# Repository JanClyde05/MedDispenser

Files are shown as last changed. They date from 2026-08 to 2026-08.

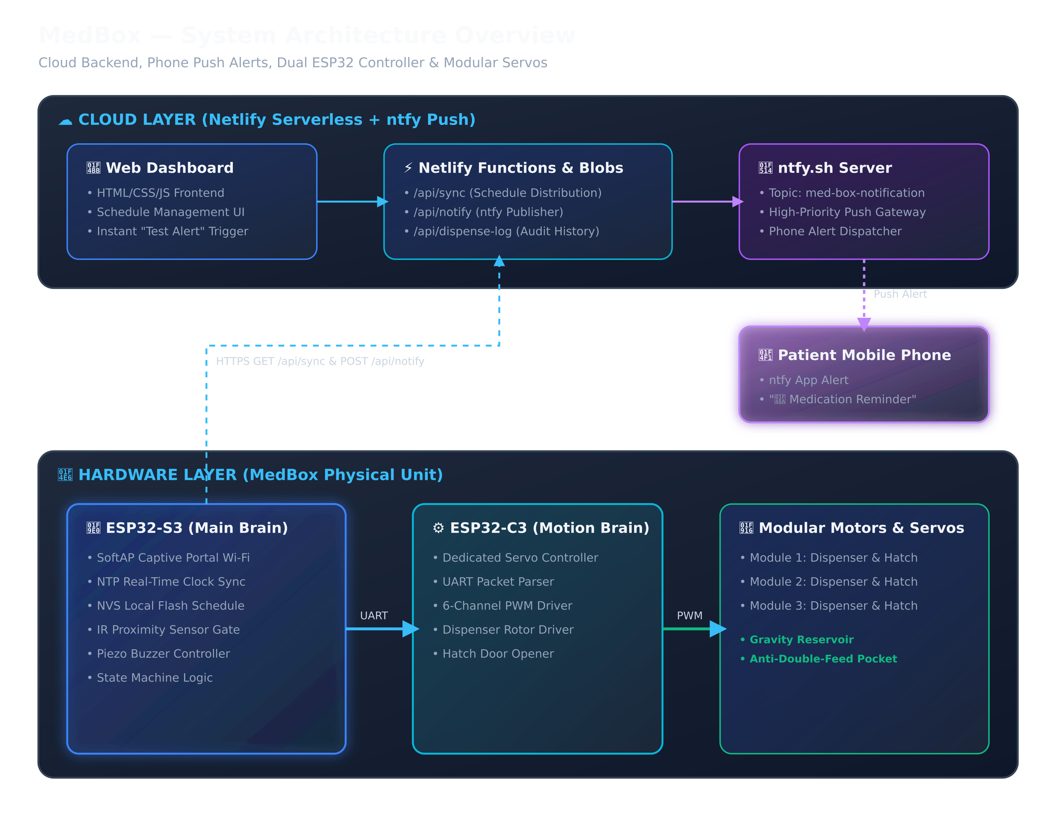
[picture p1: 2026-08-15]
MedDispenser/docs/diagrams/1_system_architecture.jpg

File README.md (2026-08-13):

[MedBox_Final_Project_Specification.md](https://github.com/user-attachments/files/31040068/MedBox_Final_Project_Specification.md)
# Modular Smart Medication Dispenser / MedBox
## Detailed Project Specification, Architecture, Mechanical Concept, Electronics, Firmware, IoT, and Expansion Plan

> **Project status:** Consolidated and finalized based on the design discussion so far.
>
> **Scope:** Commissioned prototype for a Wi-Fi-enabled medication reminder and automatic dispensing box intended for a client who has scheduled maintenance medicines.
>
> **Important scope note:** This document describes an engineering prototype architecture. It should not be represented as a medically certified dosing device. Reliable dispensing must be validated with the specific tablet/capsule types the client intends to use.

---

# 1. Project Overview

The MedBox is a modular medication reminder and dispensing system.

A user/client will use a web application to configure:

- medicine/type of medicine
- which medicine module contains it
- date
- time
- number of tablets/capsules per intake
- recurring schedule

At the configured medication time:

1. The system reaches the scheduled intake time.
2. The MedBox activates its local buzzer.
3. A push notification is sent to the user's phone through **ntfy**.
4. The system waits for the medicine taker to be in the vicinity.
5. A **proximity/IR sensor** on the main module detects the user.
6. The appropriate medication module opens its hatch.
7. The dispensing mechanism releases the configured amount of medicine.
8. The user takes the medicine from the pickup/hatch area.
9. The hatch closes.
10. The event is recorded as completed.

If the taker is not nearby, the system does **not** open the hatch. The reminder can repeat after the configured reminder interval; the current concept is **5 minutes**.

---

# 2. Core Product Concept

The MedBox is designed around one key principle:

> **One medication type = one medication module.**

The **main module is also a complete medication module**. It is not merely an electronics enclosure.

This means:

- The main module contains the first medication reservoir and dispensing mechanism.
- The main module also contains the system electronics and sensors.
- Optional expansion modules can be attached when additional medicine types are needed.
- Every medication module uses the same mechanical dispensing concept with **two servo motors**:
  - one servo for medicine dispensing
  - one servo for hatch opening/closing

Examples:

### One medication

```text
[ MAIN MODULE ]
Medicine A
```

### Two medications

```text
[ MAIN MODULE ] [ EXPANSION 2 ]
Medicine A       Medicine B
```

### Three medications

```text
[ MAIN MODULE ] [ EXPANSION 2 ] [ EXPANSION 3 ]
Medicine A       Medicine B       Medicine C
```

The system therefore does not force the user to install unnecessary expansion modules.

---

# 3. Finalized System Architecture

```text
                         ┌─────────────────────────┐
                         │       WEB APP           │
                         │   Netlify Hosted UI     │
                         │                         │
                         │ Medicine                │
                         │ Module                  │
                         │ Dose                    │
                         │ Date                    │
                         │ Time                    │
                         │ Schedule                │
                         └────────────┬────────────┘
                                      │
                                    HTTPS
                                      │
                                      ▼
                         ┌─────────────────────────┐
                         │        BACKEND          │
                         │                         │
                         │ Netlify Functions       │
                         │ Database                │
                         │ Schedule/API logic      │
                         └───────┬─────────┬───────┘
                                 │         │
                                 │         └──────────► ntfy
                                 │                       │
                                 │                       ▼
                                 │                     Phone
                                 │
                              HTTPS sync
                                 │
                                 ▼
              ┌───────────────────────────────────────────┐
              │             MAIN MED MODULE               │
              │                                           │
              │ ESP32-S3 SuperMini                        │
              │   Main IoT / system brain                 │
              │                                           │
              │ ESP32-C3 SuperMini                        │
              │   Dedicated servo controller              │
              │                                           │
              │ Proximity / IR sensor                     │
              │ Buzzer                                    │
              │ USB-C power input                         │
              │                                           │
              │ Medicine reservoir                        │
              │ Spiral/rotary dispenser                   │
              │ Dispenser Servo                           │
              │ Hatch Servo                               │
              └──────────────────┬────────────────────────┘
                                 │
                                 │ module expansion
                                 ▼
                    ┌──────────────────────────┐
                    │   EXPANSION MODULE #2    │
                    │                          │
                    │ Medicine reservoir       │
                    │ Spiral/rotary dispenser  │
                    │ Dispenser Servo          │
                    │ Hatch Servo              │
                    └────────────┬─────────────┘
                                 │
                                 ▼
                    ┌──────────────────────────┐
                    │   EXPANSION MODULE #3    │
                    │                          │
                    │ Medicine reservoir       │
                    │ Spiral/rotary dispenser  │
                    │ Dispenser Servo          │
                    │ Hatch Servo              │
                    └──────────────────────────┘
```

---

# 4. Controller Responsibilities

## 4.1 ESP32-S3 SuperMini — Main Brain

The ESP32-S3 is the primary controller.

Responsibilities:

- Wi-Fi
- communication with the web/backend system
- medication schedule synchronization
- local schedule storage
- time management
- NTP synchronization when available
- optional RTC support
- medication event state machine
- user-presence detection
- buzzer control
- communication with the ESP32-C3
- ntfy-related backend/device integration as applicable
- error handling
- system status
- logging/synchronization

The S3 is the system's "brain."

It understands concepts such as:

```text
Medicine A
Module 1
07:00 AM
1 tablet
Monday-Friday
```

The S3 does not need to directly generate every servo movement itself.

---

## 4.2 ESP32-C3 SuperMini — Dedicated Servo Controller

The ESP32-C3 is intentionally retained as a separate controller.

Its role is specifically actuator/servo control.

Responsibilities:

- control the dispenser servo for each module
- control the hatch servo for each module
- receive commands from the ESP32-S3
- execute servo movement
- optionally report command reception/completion

Conceptually:

```text
ESP32-S3
   │
   │ UART / command interface
   ▼
ESP32-C3
   │
   ├── Main module dispenser servo
   ├── Main module hatch servo
   ├── Expansion #2 dispenser servo
   ├── Expansion #2 hatch servo
   ├── Expansion #3 dispenser servo
   └── Expansion #3 hatch servo
```

The C3 does not need to know about:

- medicine names
- users
- schedules
- Wi-Fi APIs
- ntfy messages
- database records

It acts as the servo/actuator layer.

---

# 5. Why Two ESP32s Are Used

The chosen architecture intentionally separates:

### High-level logic

Handled by ESP32-S3:

```text
Internet
Wi-Fi
Schedule
Medicine
Notifications
User presence
System state
```

### Low-level actuator control

Handled by ESP32-C3:

```text
Servo
Servo
Servo
Servo
Servo
Servo
```

This keeps the software responsibilities clean and allows the compact C3 to act as a dedicated motion controller while the S3 handles the IoT workload.

---

# 6. Medication Module Architecture

Every medication module has the same mechanical concept.

## 6.1 Main Module

The main module contains:

- ESP32-S3 SuperMini
- ESP32-C3 SuperMini
- USB-C input
- power distribution
- proximity/IR sensor
- buzzer
- first medicine reservoir
- first dispensing mechanism
- first dispenser servo
- first hatch servo

Thus, the main module is both:

1. **Medication Module #1**
2. **System Controller**

---

## 6.2 Expansion Module

Each expansion module contains:

- cylindrical medicine storage container
- mechanical gravity-feed path
- spiral/rotary metering dispenser
- dispenser servo
- hatch servo

Expansion modules intentionally avoid adding another microcontroller unless the design later proves that local intelligence is necessary.

The base design is:

```text
Expansion module =
mechanics + 2 servos
```

---

# 7. Main Module vs. Expansion Module

## Main Module

```text
┌────────────────────────────────────────┐
│              MAIN MODULE               │
│                                        │
│ ESP32-S3 SuperMini                     │
│ ESP32-C3 SuperMini                     │
│ Proximity / IR sensor                  │
│ Buzzer                                 │
│ USB-C power                            │
│                                        │
│ Medicine reservoir                     │
│ Spiral/rotary dispenser                │
│ Dispenser Servo                        │
│ Hatch Servo                            │
└────────────────────────────────────────┘
```

## Expansion Module

```text
┌─────────────────────────────┐
│      EXPANSION MODULE       │
│                             │
│ Medicine reservoir          │
│ Spiral/rotary dispenser     │
│ Dispenser Servo             │
│ Hatch Servo                 │
└─────────────────────────────┘
```

---

# 8. Power Architecture

## 8.1 Main Power Source

The intended power input is a **USB-C receptacle** on the main module.

The whole system is designed around a standard 5 V USB-C phone charger/power source.

The design should provide a dedicated power path for:

- ESP32-S3
- ESP32-C3
- servos
- other low-current peripherals

The important principle is:

> **The servos are powered from the main 5 V supply/servo power rail, not through the ESP32's 5 V pin as a servo power source.**

---

## 8.2 Recommended power topology

```text
                   USB-C INPUT
                     5 V
                      │
                Power Protection
                      │
                5 V Main Bus
                      │
          ┌───────────┴───────────┐
          │                       │
          ▼                       ▼
      ESP32-S3                SERVO POWER
      ESP32-C3                    │
      sensors                     │
      buzzer               ┌──────┼──────┐
                           ▼      ▼      ▼
                          Servo  Servo  Servo...
```

All grounds should share a common reference.

```text
ESP32 GND ───────────── Servo GND
```

---

## 8.3 USB-C power considerations

The charger should be treated as a **known power source**, not assumed to always provide a particular current simply because it uses USB-C.

For the prototype:

- use a known 5 V charger/source
- preferably use a supply with enough current headroom for the maximum number of simultaneous servo movements
- do not assume every USB-C charger automatically provides 3 A
- size wiring and traces for servo current
- consider adding a fuse or current-limiting protection to the servo branch
- consider bulk capacitance near the servo power rail to help with transient servo current demand

If the final system can contain several simultaneously active servos, use a supply with comfortable current margin.

---

# 9. USB-C Protection

The main USB-C receptacle requires appropriate protection.

The original plan discussed using diodes.

A conventional diode can be used for reverse-polarity protection where appropriate, but its forward-voltage drop should be considered because the system runs from a nominal 5 V rail.

For a more optimized PCB design, alternatives such as a MOSFET-based reverse-polarity protection circuit can be evaluated because they can reduce voltage drop.

Protection should be designed according to the actual fault being prevented.

Potential protection areas:

- reverse polarity
- accidental power injection
- overcurrent
- ESD/transient events
- hot-plugging

---

# 10. Important USB-C Rule

The design should use **one intentional external power input** for the system.

Avoid having multiple user-accessible power inputs that could allow two independent chargers to be connected to the same power rails simultaneously.

Preferred:

```text
ONE USB-C INPUT
      │
      ├── S3
      ├── C3
      └── Servo power
```

---

# 11. Servo Power and Servo Control

Servo control and servo power are separate concepts.

### Control

The ESP32-C3 generates the servo control signal.

### Power

The servo receives power directly from the dedicated 5 V servo rail.

Conceptually:

```text
ESP32-C3 GPIO ───── Signal ─────► Servo
5V SERVO BUS ────── 5V ─────────► Servo
Common GND ──────── GND ────────► Servo
```

This prevents the servo current from being routed through the microcontroller's logic power path.

---

# 12. Servo Count

Each medication module uses:

### Servo #1 — Dispenser

Controls the rotary/spiral medicine metering mechanism.

### Servo #2 — Hatch

Opens/closes access to the medication pickup area.

For three total medication modules:

```text
Module 1 = 2 servos
Module 2 = 2 servos
Module 3 = 2 servos

Total = 6 servos
```

---

# 13. Mechanical Dispensing Concept

The original screw/auger concept was reconsidered.

The finalized concept is a:

> **Cylindrical gravity-fed medicine reservoir + rotary/spiral metering dispenser**

The intended behavior is similar to a controlled egg-like or pocketed arrangement, but adapted for tablets/capsules.

---

# 14. Cylindrical Medicine Container

Medicine is stored vertically in a cylinder.

Conceptually:

```text
        CYLINDER
   ┌──────────────────┐
   │ ○ ○ ○ ○ ○ ○ ○ ○  │
   │ ○ ○ ○ ○ ○ ○ ○ ○  │
   │ ○ ○ ○ ○ ○ ○ ○ ○  │
   │ ○ ○ ○ ○ ○ ○ ○ ○  │
   │        ↓         │
   │        ↓         │
   └────────┬─────────┘
            ▼
      Metering section
```

Gravity feeds medicine toward the bottom.

This avoids the need for an active auger throughout the entire storage volume.

---

# 15. Spiral / Flower-Hopper Metering Mechanism

The bottom section uses a spiral/rotary structure that meters the medicine.

Conceptually:

```text
      STORAGE CYLINDER
             │
             ▼
      ┌─────────────┐
      │ FLOW /      │
      │ HOPPER      │
      │             │
      │  SPIRAL     │
      │    ↘        │
      │      ↘      │
      │        ↘    │
      └────────┬────┘
               ▼
             DROP
```

The spiral geometry is intended to:

- control the release point
- separate adjacent tablets/capsules
- prevent uncontrolled dumping
- meter a predictable amount per indexed servo movement
- provide a mechanical anti-double-feed function

---

# 16. Mechanical Anti-Double-Feed Principle

The preferred design is to let the geometry itself prevent multiple tablets from entering the dispensing point.

The design should attempt to make:

```text
One indexed movement → One intended dispensing event
```

rather than relying entirely on software timing.

The rotary section should act as both:

1. metering mechanism
2. physical gate against a second pill following immediately

---

# 17. Servo Indexing

The exact angular step is **not finalized yet**.

An early idea was:

```text
5° movement → one medicine
```

but this should not be assumed until the actual mechanical geometry is built and calibrated.

A better implementation is:

```text
Position 0 → closed/home
Position 1 → next dispensing pocket
Position 2 → next dispensing pocket
Position 3 → next dispensing pocket
```

The servo step should be derived from the physical pocket/spiral design.

If a rotor has equally spaced pockets:

```text
servo angle per pocket = 360° / number_of_pockets
```

For example, a 24-position rotor would provide:

```text
360° / 24 = 15° per position
```

The exact number of positions should be determined experimentally.

---

# 18. Firmware Abstraction for Dispensing

The firmware should not hard-code the idea that "5° means one pill."

Instead, high-level firmware should issue:

```cpp
dispensePill();
```

or:

```text
DISPENSE MODULE 1
```

The calibrated dispenser driver handles the required servo movement.

This allows the mechanical design to be refined without rewriting the entire software architecture.

---

# 19. Spring / Feed Concept

A spring-loaded medicine feed was considered, but the design has moved toward a **gravity-fed cylinder**.

Therefore the primary planned concept is:

```text
Vertical cylinder
      ↓
Gravity
      ↓
Spiral/rotary metering hopper
      ↓
Controlled release
```

A spring may still be used later if testing shows that certain pills/capsules fail to feed reliably, but it is not the current primary design.

---

# 20. Medicine Compatibility

The dispensing mechanism must be tested using the actual medication types expected by the client.

Different medicines have different:

- diameters
- thicknesses
- shapes
- surface friction
- capsule/tablet geometry
- tendency to bridge or jam

Examples:

```text
Round tablet      ●
Oval tablet       ◉
Caplet             ▬
Capsule           ◯━━◯
Irregular tablet  custom shape
```

The mechanism should therefore be designed around a specified acceptable size range or a defined medicine list.

Do not assume one geometry will automatically work reliably for every medicine.

---

# 21. Proximity / IR Sensor

A critical clarification:

> **The IR/proximity sensor is NOT a pill-drop sensor.**

Its only role is:

> **Detect whether the medicine taker is in the vicinity of the MedBox.**

The sensor is used to enforce the hatch-opening condition.

It is not used to verify whether a tablet was dispensed.

---

# 22. User-Presence Logic

At medication time:

```text
Medication time reached
        ↓
Reminder
        ↓
Check proximity sensor
        ↓
User nearby?
      /     \
    NO       YES
    │          │
    ▼          ▼
Keep        Open hatch
reminding      │
               ▼
           Dispense medicine
               │
               ▼
           User takes medicine
```

The hatch should not open simply because the schedule has reached its time.

The proximity condition must be satisfied first.

---

# 23. No Pill-Drop IR Confirmation

The project does **not** require an additional IR sensor in the dispensing chute to prove that a pill fell.

The sequence is therefore not:

```text
Dispense
↓
Pill sensor
↓
Confirm pill
```

Instead, the mechanism is expected to dispense according to its calibrated mechanical design.

Possible future enhancements may include weight sensing, optical confirmation, or other verification, but these are **not part of the current finalized base design**.

---

# 24. Hatch

Every medication module has a hatch controlled by its own hatch servo.

Purpose:

- restrict access to the medicine
- keep the medicine compartment closed when not being taken
- help reduce unnecessary exposure/contamination
- only expose the pickup area when the user is present

The main module and every expansion module use the same hatch concept.

---

# 25. Recommended Hatch State Handling

Although a pill confirmation sensor is not required, a future or preferred reliability enhancement is a hatch-position sensor.

Possible implementations:

- magnetic reed switch
- Hall-effect sensor
- limit switch

The purpose is to tell the controller whether the hatch is physically open or closed.

Conceptually:

```text
Open command
   ↓
Hatch servo
   ↓
Hatch position sensor
   ↓
OPEN confirmed
```

This is a mechanical-state check, not a pill-detection check.

---

# 26. Buzzer

The main module contains the local notification buzzer.

At the configured medication time:

```text
Buzzer ON
```

The buzzer can continue or repeat according to the firmware's reminder policy.

A future UI can allow settings such as:

- reminder sound duration
- repeat interval
- number of reminders
- quiet mode

The initial requirement is:

> **Reminder repeats after 5 minutes if the medication has not yet been taken/handled according to the system flow.**

---

# 27. Notification System — ntfy

The project intends to use **ntfy** for phone push notifications.

ntfy can be used as a notification channel so the user receives a message when medication is due.

Conceptually:

```text
Schedule reaches medication time
             ↓
        Backend / system
             ↓
          ntfy publish
             ↓
       User's phone
             ↓
       Push notification
```

Example notification:

```text
Medication Reminder

Medicine: Medicine A
Dose: 1 tablet
Time: 7:00 AM
Module: 1

Please take your scheduled medication.
```

---

# 28. ntfy Security

Do not expose a privileged ntfy publishing credential in browser-side JavaScript.

Preferred architecture:

```text
Web Browser
    ↓
Netlify Function / Backend
    ↓
ntfy API
    ↓
Phone
```

Credentials should remain server-side as environment/secrets.

The browser should not receive a token that lets anyone publish arbitrary messages to the private notification channel.

---

# 29. Netlify Architecture

Netlify is used primarily for the web/software side.

Recommended structure:

```text
Netlify
├── Frontend / Web UI
├── Server-side Functions
└── Database
```

The web application is used to configure medications and schedules.

The backend handles:

- storing medication data
- storing schedules
- serving API endpoints
- synchronizing device data
- triggering push notifications where applicable

---

# 30. WebSocket Decision

A WebSocket architecture is **not required for the base system**.

A simpler architecture is:

```text
Web UI
  ↓
HTTPS API
  ↓
Backend/database
  ↓
ESP32 schedule synchronization
```

The ESP32 should maintain its own local schedule after synchronization.

This is preferable to requiring a continuously active WebSocket connection for medication execution.

---

# 31. Local Device Operation

The ESP32 should not depend on the Internet at the exact medication time.

Recommended design:

```text
Internet available
      ↓
ESP32 synchronizes schedule
      ↓
Schedule stored locally
      ↓
Internet temporarily unavailable
      ↓
ESP32 still follows the saved schedule
```

This prevents a temporary Wi-Fi failure from automatically disabling the basic medication schedule.

---

# 32. Timekeeping

The preferred time architecture is:

### Primary

NTP synchronization while connected to Wi-Fi.

### Recommended reliability enhancement

Use an RTC such as a DS3231 for persistent local timekeeping.

Conceptually:

```text
Internet
   ↓
NTP sync
   ↓
ESP32 time
   +
RTC backup
```

The device should not rely exclusively on `millis()` for real calendar scheduling.

---

# 33. Medication Schedule Data

The web interface should allow at minimum:

- medication name/type
- module number
- dosage/number of pills
- time
- date
- recurring days
- start date
- end date
- enabled/disabled state

Example:

```text
Medicine:
Metformin

Module:
1

Dose:
1 tablet

Time:
07:00 AM

Days:
Monday
Tuesday
Wednesday
Thursday
Friday

Start:
08/15/2026

End:
08/22/2026

Enabled:
YES
```

---

# 34. Suggested Web UI

A medication entry screen can contain:

```text
MEDICATION

Medicine name:
[________________________]

Module:
[ Module 1 ▼ ]

Dose:
[ 1 ▼ ] tablet(s)

Time:
[ 07:00 AM ]

Days:
[ Mon ] [ Tue ] [ Wed ] [ Thu ] [ Fri ] [ Sat ] [ Sun ]

Start date:
[ MM/DD/YYYY ]

End date:
[ MM/DD/YYYY ]

[ SAVE MEDICATION ]
```

The dashboard can then show:

```text
TODAY'S MEDICATIONS

07:00 AM
Medicine A
1 tablet
Module 1

12:00 PM
Medicine B
2 tablets
Module 2

08:00 PM
Medicine C
1 tablet
Module 3
```

---

# 35. Suggested Database Structure

A practical starting structure is:

## PATIENT

```text
id
name
notification_topic
created_at
```

## MEDICATION

```text
id
patient_id
name
dosage
module_id
pills_per_dose
active
```

## SCHEDULE

```text
id
medication_id
time
days_of_week
start_date
end_date
enabled
```

## DISPENSE LOG

```text
id
medication_id
module_id
scheduled_time
actual_time
requested_quantity
status
error
```

The exact schema can be changed when implementing the application.

---

# 36. Example Event Log

The website can display:

```text
MEDICATION HISTORY

08/13 07:00
Medicine A
1 tablet
DISPENSED / COMPLETED

08/13 12:00
Medicine B
2 tablets
DISPENSED / COMPLETED

08/13 20:00
Medicine C
1 tablet
REMINDER PENDING
```

The base project can log the system's commanded event and completion state.

More advanced verification can be added later.

---

# 37. Medication Event State Machine

The firmware should be designed around explicit states rather than one large collection of unrelated `if` statements.

Recommended states:

```cpp
enum SystemState {
    IDLE,
    REMINDER,
    WAITING_FOR_USER,
    HATCH_OPENING,
    DISPENSING,
    USER_TAKING_MEDICINE,
    HATCH_CLOSING,
    COMPLETED,
    ERROR_STATE
};
```

Conceptual flow:

```text
IDLE
  ↓
REMINDER
  ↓
WAITING_FOR_USER
  ↓
HATCH_OPENING
  ↓
DISPENSING
  ↓
USER_TAKING_MEDICINE
  ↓
HATCH_CLOSING
  ↓
COMPLETED
  ↓
IDLE
```

---

# 38. Complete Medication Sequence

The finalized base sequence is:

```text
1. Scheduled medication time reached
           ↓
2. Activate buzzer
           ↓
3. Trigger ntfy notification
           ↓
4. Wait/check for user proximity
           ↓
5. If user is not present:
       continue reminder policy
       wait 5 minutes
       check again
           ↓
6. If user is present:
       open the appropriate module hatch
           ↓
7. Dispense the configured medication amount
           ↓
8. Allow user to retrieve medication
           ↓
9. Close hatch
           ↓
10. Record/log event as completed
```

---

# 39. Proximity Condition

The system should avoid the following behavior:

```text
07:00
↓
Hatch immediately opens
↓
Nobody present
```

Instead:

```text
07:00
↓
Reminder
↓
Check proximity
↓
No person
↓
Keep hatch closed
```

Then:

```text
Person enters vicinity
↓
Proximity detected
↓
Hatch permitted to open
```

This is part of the project's cleanliness/access-control concept.

---

# 40. Reminder Retry

Initial requirement:

> If the medication has not yet been taken/handled, the reminder repeats after approximately 5 minutes.

Conceptually:

```text
07:00
Reminder

07:00–07:05
Wait for user

07:05
Reminder again if still pending
```

Exact reminder persistence, maximum retries, and escalation rules are configurable future software requirements.

---

# 41. Servo Command Protocol

The S3 and C3 can communicate over UART.

Example high-level commands:

```text
DISPENSE,1
OPEN,1
CLOSE,1
```

where the last number identifies the medication module.

Examples:

```text
DISPENSE,1
OPEN,1
CLOSE,1

DISPENSE,2
OPEN,2
CLOSE,2

DISPENSE,3
OPEN,3
CLOSE,3
```

The C3 can reply with acknowledgements:

```text
OK,DISPENSE,1
OK,OPEN,1
OK,CLOSE,1
```

Additional error responses can be defined later.

---

# 42. Module Mapping

Example for three medicine modules:

```text
Module 1
  Dispenser Servo → Servo A
  Hatch Servo     → Servo B

Module 2
  Dispenser Servo → Servo C
  Hatch Servo     → Servo D

Module 3
  Dispenser Servo → Servo E
  Hatch Servo     → Servo F
```

The ESP32-C3 is responsible for controlling these actuator channels.

The final GPIO mapping should be selected only after accounting for:

- ESP32-C3 board pin availability
- boot/strapping constraints
- UART connection to the S3
- servo control pins
- any debugging pins
- PCB connector routing

---

# 43. Expansion Module Electrical Concept

The user clarified that expansion modules do not carry proximity sensors.

The current simplified module concept is therefore:

```text
Expansion module
├── 5V
├── GND
├── dispenser servo signal
└── hatch servo signal
```

Depending on the finalized connector and PCB routing, additional dedicated grounds/signals can be included for reliability.

Because the expansion module does not contain its own MCU, there is no need for a full local controller interface.

---

# 44. Mechanical Connection

The physical concept is:

> **Slide an additional medicine module beside the main module.**

The modules should have a physical locking mechanism so they do not move apart during use.

Possible mechanical approaches:

- slide rails
- dovetail profile
- tongue-and-groove
- keyed mechanical latch
- spring latch

The final design should combine:

1. mechanical alignment
2. electrical contact
3. secure retention
4. easy removal

---

# 45. Main Module as the Minimum Product

The smallest valid product configuration is:

```text
┌─────────────────────────┐
│       MAIN MODULE       │
│                         │
│ Medicine A              │
│ Dispenser               │
│ Hatch                   │
│ ESP32-S3                │
│ ESP32-C3                │
│ Proximity sensor        │
│ Buzzer                  │
│ USB-C                   │
└─────────────────────────┘
```

No expansion module is necessary for a user with only one medication type.

This is an important product design principle.

---

# 46. Expansion Product Model

The system scales linearly:

```text
1 medicine:
Main module

2 medicines:
Main + expansion

3 medicines:
Main + 2 expansions

4 medicines:
Main + 3 expansions
```

The exact maximum number of modules is a future design limit based on:

- GPIO availability
- servo supply capacity
- mechanical dimensions
- connector capacity
- current draw
- communication architecture

---

# 47. Why the Main Module Still Has Two Servos

The main module is not only the "controller box."

It also dispenses Medicine #1.

Therefore it has:

```text
Servo 1 = medicine dispenser
Servo 2 = hatch
```

This is identical in mechanical function to an expansion module.

The main module merely contains **additional electronics and sensors**.

---

# 48. Optional Future Enhancements

These are not mandatory for the base prototype but can be considered after the core mechanism works.

## 48.1 Hatch Position Sensor

Confirms physically open/closed state.

## 48.2 Low Medicine Level Detection

Could be estimated from a starting count:

```text
starting quantity
-
successful scheduled doses
=
estimated remaining quantity
```

Or later improved with a physical sensor.

## 48.3 Physical Acknowledge Button

Can require user interaction before dispensing.

Example:

```text
Reminder
↓
User presses TAKE
↓
Presence detected
↓
Hatch opens
```

This can provide an additional confirmation step.

## 48.4 Display

A small OLED/TFT can show:

```text
07:00 AM

Medicine A
1 tablet

Please take medicine
```

## 48.5 Local Controls

Future buttons can provide:

- manual setup
- Wi-Fi status
- module testing
- servo calibration
- maintenance mode

---

# 49. Safety and Reliability Considerations

Even though the base project is not using pill confirmation sensing, several protections are recommended.

At minimum:

- keep the hatch closed until the user is present
- use a controlled/mechanically indexed dispenser
- use a dedicated servo power rail
- provide power protection
- prevent accidental continuous servo activation
- have a firmware error state
- provide a maintenance/manual service mode
- prevent multiple medication schedules from issuing contradictory commands
- store the schedule locally on the device
- avoid depending exclusively on continuous Internet availability
- keep notification credentials out of frontend code

---

# 50. Recommended Prototype Development Order

Do not attempt the entire system at once.

Build in this order.

## Phase 1 — Mechanical dispenser

Build one module only.

Verify:

```text
Medicine storage
↓
Gravity feed
↓
Spiral/rotary mechanism
↓
One controlled drop
```

Test real tablets/capsules.

---

## Phase 2 — Two-servo module

Add:

```text
Dispenser servo
Hatch servo
```

Verify:

```text
servo movement
home position
dispensing position
hatch open
hatch close
```

---

## Phase 3 — ESP32-C3 Servo Controller

Implement:

```text
S3 → C3 command
C3 → servo movement
C3 → acknowledgement
```

Test all six servo outputs if building the three-module version.

---

## Phase 4 — Main ESP32-S3

Add:

- Wi-Fi
- local scheduling
- time
- buzzer
- proximity sensor
- device state machine

---

## Phase 5 — User Presence

Implement:

```text
scheduled time
↓
buzzer
↓
proximity
↓
hatch permission
```

---

## Phase 6 — Web Application

Implement:

- medicine entry
- module selection
- dosage
- schedule
- date
- time
- enabled/disabled

---

## Phase 7 — Backend

Implement:

- API
- database
- schedule storage
- device synchronization

---

## Phase 8 — ntfy

Implement:

```text
Medication event
↓
backend
↓
ntfy
↓
phone
```

---

## Phase 9 — Expansion

Add:

```text
Module 2
Module 3
```

and verify the same mechanism works for every module.

---

# 51. Recommended First MVP

The first working prototype should contain only:

```text
MAIN MODULE
├── ESP32-S3
├── ESP32-C3
├── USB-C
├── Proximity sensor
├── Buzzer
├── 1 medicine cylinder
├── 1 spiral/rotary dispenser
├── 1 dispenser servo
└── 1 hatch servo
```

The MVP sequence:

```text
Set test schedule
        ↓
Time reached
        ↓
Buzzer
        ↓
Person enters vicinity
        ↓
Proximity detected
        ↓
Hatch opens
        ↓
Dispenser servo indexes
        ↓
Medicine drops
        ↓
User retrieves medicine
        ↓
Hatch closes
        ↓
System returns to IDLE
```

Only once this works reliably should the cloud layer and additional modules be integrated.

---

# 52. Finalized Design Summary

## Controllers

### ESP32-S3 SuperMini

**Main brain / IoT**

- Wi-Fi
- web/API
- schedule
- local scheduling
- time
- ntfy integration
- system logic
- proximity logic
- buzzer
- S3↔C3 communication

### ESP32-C3 SuperMini

**Dedicated servo controller**

- all dispenser servos
- all hatch servos
- actuator command execution

---

## Main Module

Contains:

- ESP32-S3
- ESP32-C3
- USB-C power input
- power distribution
- proximity/IR sensor
- buzzer
- Medicine Module #1
- dispenser servo
- hatch servo
- cylindrical medicine reservoir
- spiral/rotary dispenser

---

## Expansion Module

Contains:

- cylindrical medicine reservoir
- spiral/rotary dispenser
- dispenser servo
- hatch servo
- mechanical/electrical attachment interface

No expansion MCU is required in the base design.

---

## Power

```text
USB-C 5V
   ↓
Protection
   ↓
5V system bus
   ├── ESP32-S3
   ├── ESP32-C3
   └── dedicated servo rail
```

Servos are not intended to be powered through the ESP32's logic power path.

---

## Medicine Dispensing

Final mechanical concept:

```text
Cylinder reservoir
       ↓
Gravity
       ↓
Spiral / flower-hopper style metering mechanism
       ↓
Indexed servo rotation
       ↓
Controlled medicine release
```

The exact servo angle and spiral geometry must be calibrated experimentally.

---

## Presence Detection

The proximity/IR sensor:

- detects the medicine taker's presence
- prevents the hatch from opening when nobody is nearby

It is **not** a medicine-drop confirmation sensor.

---

## Notifications

Use:

- local buzzer
- ntfy push notifications

Secure the ntfy publishing credentials on the backend.

---

## Internet Architecture

Preferred:

```text
Netlify Web App
      ↓
Netlify Functions/API
      ↓
Database
      ↓
ESP32 schedule synchronization
```

WebSockets are optional and not required for the base design.

---

# 53. Final Concept in One Diagram

```text
                              USER
                               │
                   ┌───────────┴───────────┐
                   │                       │
                   ▼                       ▼
                WEB APP                ntfy PUSH
                   │                       ▲
                   ▼                       │
             NETLIFY BACKEND               │
                   │                       │
                   │ schedule              │
                   ▼                       │
          ┌───────────────────────┐        │
          │     ESP32-S3          │────────┘
          │     MAIN BRAIN        │
          │                       │
          │ Wi-Fi                 │
          │ Schedule              │
          │ Time                  │
          │ Presence              │
          │ Buzzer                │
          │ System logic          │
          └──────────┬────────────┘
                     │ UART
                     ▼
          ┌───────────────────────┐
          │     ESP32-C3          │
          │   SERVO CONTROLLER    │
          └─────┬────────┬────────┘
                │        │
        ┌───────┘        └───────────┐
        ▼                            ▼
 MAIN MED MODULE                EXPANSION MODULES
 ┌─────────────────┐          ┌─────────────────────┐
 │ Cylinder        │          │ Cylinder            │
 │ Spiral dispenser│          │ Spiral dispenser    │
 │ Servo: dispense │          │ Servo: dispense     │
 │ Servo: hatch    │          │ Servo: hatch        │
 │ Proximity       │          └─────────────────────┘
 │ Buzzer          │
 └─────────────────┘

                USB-C 5V POWER
                       │
               ┌───────┴───────┐
               ▼               ▼
            LOGIC POWER    SERVO POWER
```

---

# 54. Final Engineering Principle

The most important design principle for this project is:

> **The electronics should supervise the medication process, while the mechanical dispenser should inherently control the physical dose as much as possible.**

That means:

- the S3 manages the schedule and system logic
- the C3 manages servo movement
- the proximity sensor enforces user presence
- the hatch controls access
- the spiral/rotary mechanism controls physical medicine release
- the backend manages schedules and notifications
- the local device retains enough schedule information to continue basic operation during temporary connectivity loss
- the expansion modules stay mechanically standardized

This keeps the system compact, modular, serviceable, and easier to expand.

---

# 55. Current Finalized Decisions

The following decisions are considered **final for the current design direction**:

- [x] ESP32-S3 SuperMini is the main/IoT brain.
- [x] ESP32-C3 SuperMini is used specifically for servo control.
- [x] Main module is also Medication Module #1.
- [x] Main module has the same two-servo medication mechanism as expansion modules.
- [x] Each medicine module has two servos:
  - dispenser
  - hatch
- [x] Expansion modules do not require their own microcontrollers.
- [x] System uses a USB-C 5 V power source.
- [x] Servo power is separated from the ESP32 logic power path.
- [x] Proximity/IR sensor is used to detect the medicine taker.
- [x] Proximity sensor is not used for pill-drop confirmation.
- [x] Buzzer provides a local medication reminder.
- [x] ntfy is used for push notifications.
- [x] Netlify is used for the web application/backend ecosystem.
- [x] Base architecture does not require WebSockets.
- [x] Device should store/synchronize schedules locally.
- [x] NTP is suitable for network time; an RTC is recommended for additional reliability.
- [x] Medication storage uses a cylindrical container concept.
- [x] Medicine is intended to gravity-feed downward.
- [x] Dispensing uses a spiral/rotary metering mechanism.
- [x] Mechanical anti-double-feed should be achieved through dispenser geometry as much as possible.
- [x] Main module and expansion modules share the same medicine-module concept.
- [x] Expansion is optional; one-medication users only need the main module.
- [x] First prototype should be built and validated as a single-module system before adding multiple modules and full cloud integration.

---

# 56. Items Still Requiring Engineering Validation

These are deliberately left open until prototyping:

- exact servo model
- exact number of dispensing positions
- exact servo angular step
- spiral geometry
- tablet/capsule size range
- anti-double-feed geometry
- maximum quantity per cylinder
- exact USB-C charger current requirement
- exact diode/protection circuit
- servo-rail fuse/current protection
- servo power filtering/capacitance
- exact ESP32-C3 GPIO assignment
- exact S3↔C3 UART pins
- module connector design
- mechanical slide/lock geometry
- hatch geometry
- proximity sensor model and range
- reminder persistence/retry rules
- whether a hatch position sensor will be included in the first prototype
- maximum supported number of expansion modules

These should be finalized from physical testing and PCB/mechanical constraints rather than guessed up front.

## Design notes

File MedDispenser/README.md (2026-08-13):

# MedBox — Modular Smart Medication Dispenser

## Project Structure

```
MedDispenser/
│
├── firmware/
│   ├── medbox_s3/          ESP32-S3 — Main brain (Wi-Fi, schedule, sensors)
│   ├── medbox_c3/          ESP32-C3 — Servo controller
│   ├── shared/             Shared UART protocol definitions
│   └── README.md
│
├── web/
│   ├── frontend/           Static HTML/CSS/JS web application
│   ├── netlify/            Serverless backend functions
│   ├── netlify.toml        Deployment config
│   └── README.md
│
├── docs/
│   ├── ARCHITECTURE.md     System architecture overview
│   ├── UART_PROTOCOL.md    S3↔C3 command protocol
│   ├── PIN_MAP.md          GPIO assignments
│   ├── POWER.md            Power architecture & sizing
│   └── STATE_MACHINE.md    Firmware state machine
│
└── README.md               ← you are here
```

## Quick Start

### Firmware (Arduino IDE)
1. Install ESP32 board support in Arduino IDE
2. Install required libraries: `ESP32Servo`, `ArduinoJson`
3. Copy `firmware/shared/protocol.h` into both sketch folders
4. Open `firmware/medbox_s3/medbox_s3.ino` — select ESP32-S3 board — upload
5. Open `firmware/medbox_c3/medbox_c3.ino` — select ESP32-C3 board — upload

### Web App
1. Install [Netlify CLI](https://docs.netlify.com/cli/get-started/): `npm i -g netlify-cli`
2. `cd web && netlify dev` — runs frontend + functions locally
3. Deploy: `netlify deploy --prod`

## Documentation
- Full specification: `../MD Files/MedBox_Final_Project_Specification.md`
- Obsidian knowledge base: `../ObsidianMem/`
- Architecture docs: `docs/`

## Status
🟡 Scaffold — code structure and stubs created, not yet compiled/tested.

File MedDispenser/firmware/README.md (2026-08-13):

# MedBox — Firmware

## Structure

```
firmware/
├── medbox_s3/      ESP32-S3 SuperMini — Main brain / IoT
├── medbox_c3/      ESP32-C3 SuperMini — Dedicated servo controller
└── shared/         Shared protocol definitions
```

## Arduino IDE Setup

### Board Support
1. Add ESP32 board URL in Arduino IDE Preferences:
   `https://espressif.github.io/arduino-esp32/package_esp32_index.json`
2. Install **esp32** board package via Board Manager.

### Board Selection
- **S3**: Select `ESP32S3 Dev Module` (or your SuperMini variant)
- **C3**: Select `ESP32C3 Dev Module` (or your SuperMini variant)

### Required Libraries
Install via Arduino IDE Library Manager:
- `ESP32Servo` by Kevin Harrington (for C3 servo control)
- `ArduinoJson` by Benoit Blanchon (for API JSON parsing, S3 only)
- `WiFi` (built-in with ESP32 board package)
- `Preferences` (built-in with ESP32 board package)

### Shared Protocol Header
The `shared/protocol.h` file must be present in **both** sketch folders.
Copy it manually:
```
copy shared\protocol.h medbox_s3\protocol.h
copy shared\protocol.h medbox_c3\protocol.h
```
Always edit the canonical version in `shared/` first, then copy.

## Communication
S3 ↔ C3 communicate via UART using a simple text protocol.
See `shared/protocol.h` and `docs/UART_PROTOCOL.md` for details.

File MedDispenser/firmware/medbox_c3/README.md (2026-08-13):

# MedBox C3 Firmware — ESP32-C3 SuperMini

Dedicated servo controller. Receives UART commands from S3, drives all servos.

## Modules

| File | Responsibility |
|---|---|
| `medbox_c3.ino` | Main entry, setup/loop |
| `config.h` | Servo pin map, angle constants |
| `uart_handler` | UART command parser & response |
| `servo_controller` | Servo abstraction per module |
| `protocol.h` | Shared protocol definitions (copy from `shared/`) |

## Required Library
- `ESP32Servo` by Kevin Harrington — install via Arduino IDE Library Manager

## Important Notes
- Servo angle constants in `config.h` are **placeholders** — calibrate experimentally
- `DISPENSER_STEP_ANGLE` depends on the physical spiral/rotor geometry
- Servos are attached only during movement and detached after to save power

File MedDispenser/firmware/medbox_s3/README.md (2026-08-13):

# MedBox S3 Firmware — ESP32-S3 SuperMini

Main system brain handling Wi-Fi, scheduling, time, sensors, and UART commands to C3.

## Modules

| File | Responsibility |
|---|---|
| `medbox_s3.ino` | Main entry, setup/loop, debug CLI |
| `config.h` | Pin definitions, timing constants |
| `wifi_manager` | Wi-Fi connection & reconnect |
| `time_manager` | NTP sync & time utilities |
| `schedule_manager` | Local schedule storage (NVS) & evaluation |
| `state_machine` | Medication event state machine |
| `proximity` | Proximity sensor driver |
| `buzzer` | Non-blocking buzzer with patterns |
| `uart_command` | UART protocol to C3 |
| `api_client` | HTTPS backend sync (stub) |
| `protocol.h` | Shared protocol definitions (copy from `shared/`) |

## Serial Debug Commands
Open Arduino Serial Monitor at 115200 baud:
- `status` — System status overview
- `dispense1` — Test dispense on module 1
- `open1` / `close1` — Test hatch on module 1
- `buzz` — Test buzzer
- `ping` — Ping C3
- `sync` — Force backend sync
- `help` — List commands

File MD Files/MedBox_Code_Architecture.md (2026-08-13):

# MedBox — Code Architecture Reference

> This document describes the code structure and organization of the MedBox project source code located in `MedDispenser/`.

---

## Directory Map

```
MedDispenser/
│
├── firmware/
│   ├── medbox_s3/                    ESP32-S3 SuperMini — Main Brain
│   │   ├── medbox_s3.ino             Main entry, setup/loop, debug CLI
│   │   ├── config.h                  Pin definitions, timing, constants
│   │   ├── wifi_manager.h / .cpp     Wi-Fi connection & reconnect
│   │   ├── time_manager.h / .cpp     NTP sync, time utilities
│   │   ├── schedule_manager.h / .cpp Local schedule storage (NVS)
│   │   ├── state_machine.h / .cpp    Medication event state machine
│   │   ├── proximity.h / .cpp        Proximity sensor driver
│   │   ├── buzzer.h / .cpp           Non-blocking buzzer patterns
│   │   ├── uart_command.h / .cpp     UART command interface to C3
│   │   ├── api_client.h / .cpp       Backend sync (stub)
│   │   ├── protocol.h                ← copy from shared/
│   │   └── README.md
│   │
│   ├── medbox_c3/                    ESP32-C3 SuperMini — Servo Controller
│   │   ├── medbox_c3.ino             Main entry, setup/loop
│   │   ├── config.h                  Servo pin map, angle constants
│   │   ├── uart_handler.h / .cpp     UART command parser & dispatch
│   │   ├── servo_controller.h / .cpp Per-module servo abstraction
│   │   ├── protocol.h                ← copy from shared/
│   │   └── README.md
│   │
│   ├── shared/
│   │   └── protocol.h                Canonical UART protocol definitions
│   │
│   └── README.md                     Firmware overview
│
├── web/
│   ├── frontend/                     Static HTML/CSS/JS
│   │   ├── index.html                Dashboard
│   │   ├── medications.html          Medication CRUD
│   │   ├── history.html              Dispense history
│   │   ├── settings.html             System settings
│   │   ├── css/style.css             Design system
│   │   ├── js/api.js                 Backend API client
│   │   ├── js/app.js                 Core app logic, toasts
│   │   ├── js/medications.js         Medication form handling
│   │   ├── js/schedule.js            Schedule display utilities
│   │   ├── js/history.js             History table rendering
│   │   └── README.md
│   │
│   ├── netlify/functions/            Serverless backend
│   │   ├── medications.js            Medication CRUD API
│   │   ├── schedules.js              Schedule views API
│   │   ├── dispense-log.js           Dispense event log API
│   │   ├── sync.js                   ESP32 schedule sync API
│   │   ├── notify.js                 ntfy publisher (server-side)
│   │   └── README.md
│   │
│   ├── netlify.toml                  Netlify config + API redirects
│   └── README.md                     Web stack overview
│
├── docs/
│   ├── ARCHITECTURE.md               System architecture
│   ├── UART_PROTOCOL.md              S3↔C3 command protocol
│   ├── PIN_MAP.md                    GPIO assignments
│   ├── POWER.md                      Power architecture
│   └── STATE_MACHINE.md              State machine diagram
│
└── README.md                         Project root
```

---

## Design Decisions

### Firmware Modularity
Each firmware subsystem is a `.h/.cpp` pair with `init()` and `update()` functions. The main `.ino` calls all `init()` in `setup()` and all `update()` in `loop()`. This keeps the loop non-blocking and each subsystem testable independently.

### Shared Protocol
`shared/protocol.h` is the single source of truth for the UART command format. It must be **copied** into both sketch folders for Arduino IDE compatibility. Always edit the canonical version first.

### Web Frontend
Plain HTML/CSS/JS with no build step. This matches the project's embedded-systems focus and avoids unnecessary toolchain complexity. API calls use `fetch()` wrappers in `api.js`.

### Backend Functions
Netlify Functions provide a serverless API. Each function handles one resource. Currently using in-memory stubs — the database integration point is marked with `// TODO` in each function.

### In-Repo Docs
Quick-reference docs in `docs/` are derived from the main specification but optimized for day-to-day development use (tables, diagrams, pin maps).

---

## Companion Resources

| Resource | Location |
|---|---|
| Full specification | `../MD Files/MedBox_Final_Project_Specification.md` |
| Obsidian knowledge base | `../ObsidianMem/` |
| This document | `../MD Files/MedBox_Code_Architecture.md` |

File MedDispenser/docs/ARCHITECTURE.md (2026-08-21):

# MedBox — System Architecture

> **Last Updated:** 2026-08-22 — Reflects dual-path time sync (NTP + server), 10s command polling, and HTTP/HTTPS dual compatibility.

## Overview

```
┌──────────────────────────────────────────────────────────────────────┐
│                           USER                                       │
│                            │                                         │
│              ┌─────────────┴─────────────┐                           │
│              ▼                           ▼                           │
│          WEB APP                    ntfy PUSH                        │
│          (any page)                    ▲                             │
│              │                         │                             │
│              ▼                         │                             │
│       NETLIFY BACKEND ─────────────────┘                             │
│              │                                                       │
│              │ HTTPS sync (5 min) + command poll (10s)               │
│              ▼                                                       │
│   ┌────────────────────────┐                                         │
│   │      ESP32-S3          │  Wi-Fi, Schedule, Time, Proximity,      │
│   │      MAIN BRAIN        │  Buzzer, System logic                   │
│   └───────────┬────────────┘                                         │
│               │ UART (115200 baud)                                   │
│               ▼                                                      │
│   ┌────────────────────────┐                                         │
│   │      ESP32-C3          │  Servo control for all modules          │
│   │   SERVO CONTROLLER     │                                         │
│   └───┬──────┬──────┬──────┘                                         │
│       │      │      │                                                │
│       ▼      ▼      ▼                                                │
│     MOD1   MOD2   MOD3    (each: 2 servos — dispenser + hatch)      │
│                                                                      │
│            USB-C 5V POWER                                            │
│               │                                                      │
│        ┌──────┴──────┐                                               │
│        ▼             ▼                                               │
│   LOGIC POWER   SERVO POWER                                         │
└──────────────────────────────────────────────────────────────────────┘
```

## Controller Responsibilities

| Controller | Role | Responsibilities |
|---|---|---|
| ESP32-S3 SuperMini | Main brain / IoT | Wi-Fi, API sync, schedule, NTP/RTC, server time sync, proximity, buzzer, state machine, UART to C3 |
| ESP32-C3 SuperMini | Servo controller | All dispenser servos (360° continuous rotation), all hatch servos (0°–90°), UART command execution |

## Communication
- S3 ↔ C3: UART (115200 baud), text-based command/response protocol
- S3 TX: GPIO 1 → C3 RX: GPIO 20
- S3 RX: GPIO 2 ← C3 TX: GPIO 21
- S3 ↔ Backend: HTTP/HTTPS polling (every 5 min for schedule sync, every 10s for hardware test commands)
- Backend → Phone: ntfy push notifications

## Key Design Principles
1. **Separation**: High-level logic (S3) vs actuator control (C3) vs mechanical dose control
2. **Local operation**: Device retains schedule locally in NVS Flash, operates during Internet loss
3. **Mechanical safety**: Dispenser geometry prevents double-feeding, not just software
4. **IR-gated dispensing**: Hatch opens **ONLY** when IR proximity sensor detects user hand — never simultaneously with buzzer/dispenser
5. **Dual time sync**: NTP (pool.ntp.org) as primary, server epoch from `/api/sync` response as fallback

## Servo Motor Details

### Dispenser Servo (SG90R — Modified 360° Continuous Rotation)
- **Modification**: Internal potentiometer disconnected, physical stopper removed
- **Control method**: `attach()` → `write(180)` (full speed forward) → `delay(DISPENSER_REV_TIME_MS)` → `detach()` (hard stop)
- **Why `detach()`**: Without an internal potentiometer, `write(90)` does NOT stop the motor. Only cutting the PWM signal via `detach()` forces the internal motor driver to kill power instantly.
- **Rev time**: 2400ms per 360° physical revolution (calibrated empirically)
- **Multi-pill**: For `pillsPerDose = N`, the servo runs N consecutive 2.4s revolutions with 300ms pause between each

### Hatch Servo (Standard SG90 — 0° to 90°)
- **Closed**: `write(0)` → 0° position (sealed)
- **Open**: `write(90)` → 90° position (user retrieval window)
- Uses standard `attach()` → `write(angle)` → `delay(300ms)` → `detach()`

## HTTP / HTTPS Dual Compatibility

The API client uses `_beginHttp()` helper to detect URL scheme:
- `http://` URLs: Uses plain HTTP (for local testing with `http://192.168.x.x:8888`)
- `https://` URLs: Uses HTTPS with `WiFiClientSecure` + `setInsecure()` (for Netlify deployment)

This prevents `HTTP -1` SSL errors when testing locally.

## Schedule Activation Architecture

Schedules are triggered by **two independent systems** running in parallel:

| System | Location | Mechanism |
|---|---|---|
| **Web Schedule Checker** | `app.js` (browser) | Polls `/api/medications` every 30s, sends `/api/dispense-command` when time matches |
| **ESP32 Schedule Manager** | `schedule_manager.cpp` (firmware) | Evaluates NVS-stored schedules every `loop()` iteration against NTP/server time |

Both paths converge: Web sends a dispense command → ESP32 polls it via `/api/dispense-command` every 10s. ESP32's own schedule manager can also trigger independently if time matches.

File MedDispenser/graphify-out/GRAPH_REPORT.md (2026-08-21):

# Graph Report - MedDispenser  (2026-08-22)

## Corpus Check
- 57 files · ~94,616 words
- Verdict: corpus is large enough that graph structure adds value.

## Summary
- 337 nodes · 463 edges · 36 communities (28 shown, 8 thin omitted)
- Extraction: 89% EXTRACTED · 11% INFERRED · 0% AMBIGUOUS · INFERRED: 51 edges (avg confidence: 0.85)
- Token cost: 0 input · 0 output

## Graph Freshness
- Built from commit: `d22ebba7`
- Run `git rev-parse HEAD` and compare to check if the graph is stale.
- Run `graphify update .` after code changes (no API cost).

## Community Hubs (Navigation)
- api_client.cpp
- time_manager.cpp
- wifi_manager.cpp
- servo_controller.cpp
- MedBox — Complete Device Architecture & Operation Guide
- MedBox — Complete Pin Mapping & Interconnect Specification
- data/app.js
- MedBox — UART Protocol Specification
- MedBox — System Architecture
- js/app.js
- buzzer.cpp
- Arduino IDE Setup
- js/medications.js
- settings.js
- MedBox — Local Testing Guide
- MedBox — Firmware State Machine
- package.json
- MedBox — Modular Smart Medication Dispenser
- MedBox — Power Architecture
- functions/medications.js
- MedBox — Netlify Functions
- MedBox — Web Application
- MedBox C3 Firmware — ESP32-C3 SuperMini
- MedBox — Frontend
- MedBox S3 Firmware — ESP32-S3 SuperMini
- history.js
- devices.js
- dispense-command.js
- dispense-log.js
- notify.js
- schedules.js
- sync.js
- api.js

## God Nodes (most connected - your core abstractions)
1. `stateMachineUpdate()` - 11 edges
2. `MedBox — Complete Device Architecture & Operation Guide` - 11 edges
3. `apiClientSyncSchedules()` - 9 edges
4. `_processCommand()` - 8 edges
5. `_beginHttp()` - 8 edges
6. `apiClientUpdate()` - 8 edges
7. `_getTime()` - 8 edges
8. `wifiIsConnected()` - 8 edges
9. `MedBox — System Architecture` - 8 edges
10. `wifiManagerInit()` - 7 edges

## Surprising Connections (you probably didn't know these)
- `apiClientUpdate()` --calls--> `buzzerPatternStart()`  [INFERRED]
  firmware/medbox_s3/api_client.cpp → firmware/medbox_s3/buzzer.cpp
- `apiClientSyncSchedules()` --calls--> `scheduleAdd()`  [INFERRED]
  firmware/medbox_s3/api_client.cpp → firmware/medbox_s3/schedule_manager.cpp
- `apiClientSyncSchedules()` --calls--> `scheduleClearAll()`  [INFERRED]
  firmware/medbox_s3/api_client.cpp → firmware/medbox_s3/schedule_manager.cpp
- `apiClientSyncSchedules()` --calls--> `scheduleSaveToNVS()`  [INFERRED]
  firmware/medbox_s3/api_client.cpp → firmware/medbox_s3/schedule_manager.cpp
- `apiClientSyncSchedules()` --calls--> `timeSetEpoch()`  [INFERRED]
  firmware/medbox_s3/api_client.cpp → firmware/medbox_s3/time_manager.cpp

## Import Cycles
- None detected.

## Communities (36 total, 8 thin omitted)

### Community 0 - "api_client.cpp"
Cohesion: 0.08
Nodes (28): apiClientHeartbeat(), apiClientLogDispense(), apiClientNotify(), _apiClientPollCommands(), apiClientSyncSchedules(), apiClientUpdate(), _beginHttp(), String (+20 more)

### Community 1 - "time_manager.cpp"
Cohesion: 0.16
Nodes (19): MedSchedule, scheduleAdd(), scheduleGetPending(), scheduleHasPending(), scheduleLoadFromNVS(), scheduleManagerInit(), scheduleManagerUpdate(), String (+11 more)

### Community 2 - "wifi_manager.cpp"
Cohesion: 0.16
Nodes (20): String, nvsClearWifi(), nvsGetWifiPass(), nvsGetWifiSsid(), nvsHasWifiCreds(), nvsSaveWifi(), String, _scanNetworksJson() (+12 more)

### Community 3 - "servo_controller.cpp"
Cohesion: 0.17
Nodes (12): _getDispenser(), _getHatch(), _rotatePillRevolution(), servoCloseHatch(), servoDispense(), servoHome(), servoOpenHatch(), _processCommand() (+4 more)

### Community 4 - "MedBox — Complete Device Architecture & Operation Guide"
Cohesion: 0.11
Nodes (18): 10. Revision History, 1. System Overview & Core Principles, 2. High-Level System Architecture, 3.1 ESP32-S3 SuperMini (System Brain), 3.2 ESP32-C3 SuperMini (Dedicated Servo Controller), 3. Microcontroller Responsibilities & Hardware Interconnects, 4. Electrical & Power Topology, 5. Firmware State Machine & Medication Flow (+10 more)

### Community 5 - "MedBox — Complete Pin Mapping & Interconnect Specification"
Cohesion: 0.14
Nodes (13): 1. System Interconnect Summary, 2. ESP32-S3 SuperMini (Main IoT Controller) Pin Map, 3. ESP32-C3 SuperMini (Servo Controller) Pin Map, 4.1 Module 1 (Main Box Dispenser & Hatch), 4.2 Module 2 (Expansion Unit #1), 4.3 Module 3 (Expansion Unit #2), 4.4 Proximity Sensor & Buzzer, 4. Peripherals & Actuators Connection Breakout (+5 more)

### Community 6 - "data/app.js"
Cohesion: 0.25
Nodes (11): closeModal(), connectFromModal(), connectManual(), connectToNetwork(), escapeHtml(), getSignalIcon(), pollConnectionStatus(), scanNetworks() (+3 more)

### Community 7 - "MedBox — UART Protocol Specification"
Cohesion: 0.17
Nodes (11): Command Reference, Commands (S3 → C3), Error Codes, ESP32-C3 Silicon Constraint, Extended Format: `DISPENSE,N,C`, MedBox — UART Protocol Specification, Message Format, Physical Layer (+3 more)

### Community 8 - "MedBox — System Architecture"
Cohesion: 0.18
Nodes (10): Communication, Controller Responsibilities, Dispenser Servo (SG90R — Modified 360° Continuous Rotation), Hatch Servo (Standard SG90 — 0° to 90°), HTTP / HTTPS Dual Compatibility, Key Design Principles, MedBox — System Architecture, Overview (+2 more)

### Community 9 - "js/app.js"
Cohesion: 0.33
Nodes (9): checkSchedulesNow(), loadDashboard(), loadDevices(), loadTodaySchedules(), renderDeviceHub(), renderScheduleCard(), showToast(), startScheduleChecker() (+1 more)

### Community 10 - "buzzer.cpp"
Cohesion: 0.39
Nodes (7): buzzerBeep(), buzzerInit(), buzzerPatternStart(), buzzerStop(), buzzerUpdate(), _soundOff(), _soundOn()

### Community 11 - "Arduino IDE Setup"
Cohesion: 0.22
Nodes (8): Arduino IDE Setup, Board Selection, Board Support, Communication, MedBox — Firmware, Required Libraries, Shared Protocol Header, Structure

### Community 12 - "js/medications.js"
Cohesion: 0.39
Nodes (7): deleteMedication(), getDaysArray(), getDaysBitmask(), handleSaveMedication(), loadMedications(), renderMedicationCard(), toggleMedication()

### Community 13 - "settings.js"
Cohesion: 0.28
Nodes (4): cleanTopicName(), handleSaveNotificationSettings(), handleTestNotification(), HW_COMMAND_LABELS

### Community 14 - "MedBox — Local Testing Guide"
Cohesion: 0.25
Nodes (7): 1. Running the Local Development Server, 2. Testing Frontend & Backend Features Locally, 3. Connecting Physical ESP32 Hardware to Localhost (Optional), A. Manual Test Alert & Hardware Trigger, B. Automatic Scheduled Notifications, MedBox — Local Testing Guide, Steps:

### Community 15 - "MedBox — Firmware State Machine"
Cohesion: 0.25
Nodes (7): Dispensing Sequence Detail, Error State, MedBox — Firmware State Machine, State Transition Diagram, States, Timing Constants, UART Command Spam Prevention

### Community 16 - "package.json"
Cohesion: 0.25
Nodes (7): @netlify/blobs, dependencies, @netlify/blobs, description, name, private, version

### Community 17 - "MedBox — Modular Smart Medication Dispenser"
Cohesion: 0.25
Nodes (7): Documentation, Firmware (Arduino IDE), MedBox — Modular Smart Medication Dispenser, Project Structure, Quick Start, Status, Web App

### Community 18 - "MedBox — Power Architecture"
Cohesion: 0.29
Nodes (6): Current Budget (Estimated), Key Rule, MedBox — Power Architecture, Power Supply Recommendation, Protection Considerations, Topology

### Community 19 - "functions/medications.js"
Cohesion: 0.48
Nodes (6): addToIndex(), getAllMedications(), getNextId(), { getStore, connectLambda }, handler(), removeFromIndex()

### Community 20 - "MedBox — Netlify Functions"
Cohesion: 0.33
Nodes (5): Database, Environment Variables (Netlify Dashboard), Functions, Local Development, MedBox — Netlify Functions

### Community 21 - "MedBox — Web Application"
Cohesion: 0.33
Nodes (5): Architecture, Deployment, Local Development, MedBox — Web Application, Structure

### Community 22 - "MedBox C3 Firmware — ESP32-C3 SuperMini"
Cohesion: 0.40
Nodes (4): Important Notes, MedBox C3 Firmware — ESP32-C3 SuperMini, Modules, Required Library

### Community 24 - "MedBox — Frontend"
Cohesion: 0.40
Nodes (4): Deployment, JS Modules, MedBox — Frontend, Pages

### Community 25 - "MedBox S3 Firmware — ESP32-S3 SuperMini"
Cohesion: 0.50
Nodes (3): MedBox S3 Firmware — ESP32-S3 SuperMini, Modules, Serial Debug Commands

## Knowledge Gaps
- **92 isolated node(s):** `Api`, `_triggeredSchedules`, `HW_COMMAND_LABELS`, `{ getStore, connectLambda }`, `{ getStore, connectLambda }` (+87 more)
  These have ≤1 connection - possible missing edges or undocumented components.
- **8 thin communities (<3 nodes) omitted from report** — run `graphify query` to explore isolated nodes.

## Suggested Questions
_Questions this graph is uniquely positioned to answer:_

- **Why does `stateMachineUpdate()` connect `api_client.cpp` to `time_manager.cpp`, `buzzer.cpp`?**
  _High betweenness centrality (0.009) - this node is a cross-community bridge._
- **Why does `apiClientSyncSchedules()` connect `api_client.cpp` to `time_manager.cpp`?**
  _High betweenness centrality (0.007) - this node is a cross-community bridge._
- **Why does `wifiIsConnected()` connect `api_client.cpp` to `time_manager.cpp`, `wifi_manager.cpp`?**
  _High betweenness centrality (0.006) - this node is a cross-community bridge._
- **Are the 9 inferred relationships involving `stateMachineUpdate()` (e.g. with `apiClientLogDispense()` and `apiClientNotify()`) actually correct?**
  _`stateMachineUpdate()` has 9 INFERRED edges - model-reasoned connections that need verification._
- **Are the 6 inferred relationships involving `apiClientSyncSchedules()` (e.g. with `scheduleAdd()` and `scheduleClearAll()`) actually correct?**
  _`apiClientSyncSchedules()` has 6 INFERRED edges - model-reasoned connections that need verification._
- **Are the 4 inferred relationships involving `_processCommand()` (e.g. with `servoCloseHatch()` and `servoDispense()`) actually correct?**
  _`_processCommand()` has 4 INFERRED edges - model-reasoned connections that need verification._
- **What connects `Api`, `_triggeredSchedules`, `HW_COMMAND_LABELS` to the rest of the system?**
  _92 weakly-connected nodes found - possible documentation gaps or missing edges._

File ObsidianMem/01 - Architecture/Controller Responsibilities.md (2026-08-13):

# Controller Responsibilities

## Status: FINALIZED

## ESP32-S3 SuperMini — Main Brain

- Wi-Fi connectivity
- Web/backend communication (HTTPS sync)
- Medication schedule synchronization
- Local schedule storage (NVS/Preferences)
- NTP time synchronization
- Optional RTC support
- Medication event [[State Machine|state machine]]
- Proximity/IR sensor logic (user presence)
- Buzzer control
- UART communication to [[C3 Firmware Overview|ESP32-C3]]
- Error handling and logging

## ESP32-C3 SuperMini — Servo Controller

- Receive [[UART Protocol|UART commands]] from S3
- Control dispenser servos (all modules)
- Control hatch servos (all modules)
- Send acknowledgement responses
- No Wi-Fi, no schedule knowledge, no sensor reading

## Why Two MCUs?
- Clean separation of IoT workload from real-time servo control
- C3 can drive up to 6 servos (3 modules × 2 servos) without Wi-Fi overhead
- S3 can focus on connectivity and logic without servo timing concerns

## Related
- [[System Architecture]]
- [[GPIO Map]]

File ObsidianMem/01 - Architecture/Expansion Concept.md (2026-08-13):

# Expansion Concept

## Status: FINALIZED

## Principle
> One medication type = one medication module.

## Module Configurations
- **1 medicine**: Main module only (no expansion needed)
- **2 medicines**: Main + 1 expansion
- **3 medicines**: Main + 2 expansions
- **N medicines**: Main + (N-1) expansions

## Expansion Module Contents
- Cylindrical medicine reservoir
- Spiral/rotary dispenser mechanism
- 1 dispenser servo
- 1 hatch servo
- Mechanical/electrical attachment interface

## What Expansion Modules Do NOT Have
- No MCU
- No proximity sensor
- No buzzer
- No power input

## Electrical Connection
Per expansion module: 4 signals
1. 5V (servo power)
2. GND
3. Dispenser servo signal (from C3)
4. Hatch servo signal (from C3)

## Mechanical Connection
Physical locking mechanism (NOT FINALIZED):
- Slide rails / dovetail / tongue-and-groove / keyed latch

## Maximum Modules
NOT FINALIZED — depends on C3 GPIO count, servo power budget, and mechanical size.
Current firmware supports 3 modules (1 main + 2 expansion).

## Related
- [[System Architecture]]
- [[Connectors]]
- [[GPIO Map]]

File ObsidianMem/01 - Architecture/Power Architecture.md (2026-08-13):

# Power Architecture

## Status: FINALIZED (topology), NOT FINALIZED (exact ratings)

## Topology
- Single USB-C 5V input on main module
- Power protection (reverse polarity, overcurrent, ESD)
- 5V main bus splits to logic power and servo power rail
- Common ground throughout

## Key Rule
> Servos are powered from the dedicated servo power rail, NOT through ESP32's 5V pin.

## Current Estimates
- Logic side: ~280 mA typical, ~580 mA peak
- Per module (2 servos): ~20 mA idle, ~1000 mA peak
- 3-module worst case: ~1580 mA peak (assumes 2 servos moving simultaneously)

## Recommended Supply
- Prototype (1 module): 5V 2A minimum
- Full system (3 modules): 5V 3A recommended
- Sequence servo operations to avoid simultaneous peak draw

## Protection
- Reverse polarity: Schottky diode or P-MOSFET
- Overcurrent: PTC resettable fuse on servo rail
- Transient/ESD: TVS diode on VBUS
- Bulk capacitance: 100-470 µF near servo rail
- Decoupling: 100 nF ceramic near each ESP32

## Related
- [[System Architecture]]
- [[Servo Selection]]

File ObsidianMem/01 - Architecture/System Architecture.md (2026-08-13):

# System Architecture

## Status: FINALIZED

The MedBox uses a dual-MCU architecture with a cloud backend.

## Block Diagram

```
USER → WEB APP → NETLIFY BACKEND → ESP32-S3 (UART) → ESP32-C3 → Servos
                        ↓
                   ntfy → Phone
```

## Key Components

| Component | Role |
|---|---|
| ESP32-S3 SuperMini | Main brain — Wi-Fi, schedule, sensors, buzzer |
| ESP32-C3 SuperMini | Servo controller — all dispenser + hatch servos |
| Netlify | Web frontend + serverless backend |
| ntfy | Push notifications |
| USB-C 5V | Single power input |

## Design Principles
1. **Separation of concerns**: S3 handles logic, C3 handles actuators
2. **Local-first**: Device operates from local schedule during Internet loss
3. **Mechanical safety**: Dispenser geometry prevents double-feed
4. **Presence-gated**: Hatch opens only when user is detected nearby

## Related
- [[Controller Responsibilities]]
- [[Power Architecture]]
- [[Expansion Concept]]

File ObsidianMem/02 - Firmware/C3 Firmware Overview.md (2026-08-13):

# C3 Firmware Overview

## Board: ESP32-C3 SuperMini
## Arduino IDE, Pure Arduino (no PlatformIO)

## Modules

| Module | File | Purpose |
|---|---|---|
| Main | `medbox_c3.ino` | Setup/loop |
| Config | `config.h` | Servo pin map, angle constants |
| UART | `uart_handler` | Command parser & response |
| Servos | `servo_controller` | Per-module servo abstraction |
| Protocol | `protocol.h` | Shared protocol defs |

## Architecture
- Simple command dispatcher: receive UART → parse → act → respond
- Servos attached only during movement, detached after (power saving)
- Dispenser uses incremental angle stepping
- Module ID maps to GPIO pin pair via lookup table in `config.h`

## Dependencies
- `ESP32Servo` by Kevin Harrington

## Important Notes
- `DISPENSER_STEP_ANGLE` is a placeholder — calibrate with real hardware
- `delay()` is used during servo movements — acceptable since C3's only job is servo control
- Servo min/max pulse widths may need tuning per servo model

## Related
- [[S3 Firmware Overview]]
- [[UART Protocol]]
- [[GPIO Map]]
- [[Servo Selection]]

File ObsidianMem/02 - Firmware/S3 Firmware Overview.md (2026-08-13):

# S3 Firmware Overview

## Board: ESP32-S3 SuperMini
## Arduino IDE, Pure Arduino (no PlatformIO)

## Modules

| Module | File | Purpose |
|---|---|---|
| Main | `medbox_s3.ino` | Setup/loop, debug CLI |
| Config | `config.h` | All pin defs and constants |
| Wi-Fi | `wifi_manager` | Connection & reconnect |
| Time | `time_manager` | NTP sync |
| Schedule | `schedule_manager` | Local schedule storage (NVS) |
| State Machine | `state_machine` | Medication event flow |
| Proximity | `proximity` | User presence detection |
| Buzzer | `buzzer` | Non-blocking tone patterns |
| UART | `uart_command` | S3→C3 command/response |
| API | `api_client` | Backend sync (stub) |
| Protocol | `protocol.h` | Shared protocol defs |

## Architecture
- Non-blocking state machine in `loop()`
- Each module has an `init()` and `update()` function
- No `delay()` calls in main loop (except startup)
- NVS used for persistent schedule storage

## Dependencies
- `WiFi.h` (built-in)
- `Preferences.h` (built-in)
- `ArduinoJson` (for API JSON parsing)

## Related
- [[C3 Firmware Overview]]
- [[UART Protocol]]
- [[State Machine]]
- [[Schedule Storage]]

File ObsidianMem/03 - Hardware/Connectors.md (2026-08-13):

# Connectors

## Status: NOT FINALIZED

## Purpose
Electrical + mechanical connection between main module and expansion modules.

## Signals Per Expansion Module
1. 5V (servo power)
2. GND
3. Dispenser servo signal
4. Hatch servo signal

Minimum: 4 pins. May include additional GND for reliability.

## Connector Candidates

| Connector | Pins | Pitch | Notes |
|---|---|---|---|
| JST XH | 4-5 | 2.5mm | Common, keyed, affordable |
| JST PH | 4-5 | 2.0mm | Smaller, common in hobby electronics |
| Pogo pins | 4+ | custom | No cable, direct contact, elegant |
| Magnetic pogo | 4+ | custom | Premium, easy alignment, costly |
| Board-to-board | 4+ | various | PCB stacking, compact |

## Considerations
- Must carry servo current (~1A peak per module)
- Should be mechanically robust (repeated connect/disconnect)
- Should be keyed or polarized to prevent miswiring
- Should align with mechanical locking mechanism

## Related
- [[Expansion Concept]]
- [[Power Architecture]]

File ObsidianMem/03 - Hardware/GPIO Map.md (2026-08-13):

# GPIO Map

## Status: NOT FINALIZED — placeholder assignments

## ESP32-S3 SuperMini
| GPIO | Function |
|---|---|
| 17 | UART1 TX → C3 |
| 18 | UART1 RX ← C3 |
| 5 | Proximity sensor |
| 6 | Buzzer (PWM) |

Avoid: GPIO 0, 45, 46 (strapping)

## ESP32-C3 SuperMini
| GPIO | Function |
|---|---|
| 20 | UART RX ← S3 |
| 21 | UART TX → S3 |
| 0 | M1 Dispenser servo |
| 1 | M1 Hatch servo |
| 3 | M2 Dispenser servo |
| 4 | M2 Hatch servo |
| 5 | M3 Dispenser servo |
| 6 | M3 Hatch servo |

Avoid: GPIO 2, 8 (strapping), GPIO 9 (boot button)

## Related
- [[Controller Responsibilities]]
- [[Servo Selection]]
- [[Connectors]]

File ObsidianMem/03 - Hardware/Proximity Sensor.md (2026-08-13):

# Proximity Sensor

## Status: NOT FINALIZED

## Purpose
Detect whether the medicine taker is in the vicinity of the MedBox.
**NOT** a pill-drop sensor.

## Candidates

| Sensor | Type | Range | Output | Notes |
|---|---|---|---|---|
| HC-SR501 | PIR | ~7m | Digital | Motion-based, large, warm-up delay |
| RCWL-0516 | Microwave | ~5-7m | Digital | Through-enclosure, compact |
| VL53L0X | ToF laser | ~2m | I2C (digital) | Precise distance, narrow FOV |
| GP2Y0A21 | IR analog | 10-80cm | Analog | Classic, good short range |
| APDS-9960 | Multi-sensor | ~30cm | I2C | Gesture+proximity, very short range |

## Considerations
- Range should be "nearby" (0.5-2m typical use case)
- Must not false-trigger from pets or distant movement
- Should work reliably indoors
- Power consumption matters (always-on polling)

## Recommendation
**VL53L0X** (ToF) or **RCWL-0516** (microwave) for prototype.
- VL53L0X: precise distance, can set threshold, I2C interface
- RCWL-0516: simple digital output, detects through plastic enclosure

## Related
- [[GPIO Map]]
- [[State Machine]]

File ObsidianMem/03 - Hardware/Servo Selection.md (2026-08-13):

# Servo Selection

## Status: NOT FINALIZED

## Requirements
- 5V operation (from servo power rail)
- Sufficient torque for dispenser indexing and hatch operation
- Small form factor (compact enclosure)
- Available and affordable for prototyping

## Candidates

| Model | Torque | Speed | Size | Price | Notes |
|---|---|---|---|---|---|
| SG90 | 1.8 kg·cm | 0.1s/60° | 22×11×23 mm | ~$1-2 | Common, may lack torque |
| MG90S | 2.2 kg·cm | 0.1s/60° | 22×12×30 mm | ~$3-4 | Metal gears, more reliable |
| SG92R | 2.5 kg·cm | 0.1s/60° | 23×12×29 mm | ~$2-3 | Upgraded SG90 |
| MG996R | 13 kg·cm | 0.15s/60° | 40×20×43 mm | ~$5-7 | Large — may not fit |

## Considerations
- Dispenser servo needs consistent indexing — metal gears recommended
- Hatch servo needs moderate torque — SG90 class may suffice
- Current draw varies significantly between models
- SG90-class: ~500 mA peak, MG996R: ~900 mA peak

## Recommendation
Start prototyping with **MG90S** (metal gear, compact, sufficient torque).
Validate with actual dispenser mechanism before committing.

## Related
- [[Power Architecture]]
- [[GPIO Map]]
- [[Dispenser Mechanism]]

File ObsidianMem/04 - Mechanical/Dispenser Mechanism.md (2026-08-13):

# Dispenser Mechanism

## Status: FINALIZED (concept), NOT FINALIZED (geometry/dimensions)

## Concept
Cylindrical gravity-fed reservoir → spiral/rotary/flower-hopper metering mechanism → controlled release.

## How It Works
1. Medicine stored vertically in a cylinder
2. Gravity feeds tablets/capsules downward
3. Bottom section has a spiral/rotary rotor with pockets
4. Servo indexes the rotor by one pocket per dispense
5. One indexed movement = one dispensing event
6. Geometry physically prevents a second pill from following

## Key Design Goals
- One index step = one pill (calibrated per medication)
- Mechanical anti-double-feed through rotor pocket geometry
- No reliance on software timing for dose control

## Open Items
- Exact pocket count (determines step angle: 360°/N)
- Pocket dimensions (per tablet/capsule size)
- Spiral geometry (pitch, depth, wall clearance)
- Material (3D printed prototype)
- Step angle NOT FINALIZED — placeholder is 15° (24-pocket)

## Firmware Abstraction
The S3 issues `dispensePill()` / `DISPENSE,N`.
The physical angle is handled by the C3's `config.h` constants.

## Related
- [[Hatch Design]]
- [[Medicine Compatibility]]
- [[Servo Selection]]

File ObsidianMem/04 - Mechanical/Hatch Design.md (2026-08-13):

# Hatch Design

## Status: FINALIZED (concept), NOT FINALIZED (geometry)

## Purpose
- Restrict access to medicine compartment
- Only open when user is present (proximity confirmed)
- Reduce contamination/exposure

## Servo Control
- Closed: `HATCH_CLOSED_ANGLE` (0° placeholder)
- Open: `HATCH_OPEN_ANGLE` (90° placeholder)
- Command: `OPEN,N` / `CLOSE,N` via [[UART Protocol]]

## Hatch Position Sensor
Status: OPTIONAL / NOT FINALIZED for first prototype

Possible implementations:
- Magnetic reed switch + magnet on hatch
- Hall-effect sensor
- Limit/micro switch

Purpose: confirm physical open/closed state (not pill detection).

## Timing
- Stays open for `HATCH_OPEN_WAIT_MS` (15 sec default)
- Closes automatically after timeout

## Related
- [[Dispenser Mechanism]]
- [[State Machine]]

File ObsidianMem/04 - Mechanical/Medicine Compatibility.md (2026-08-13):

# Medicine Compatibility

## Status: NOT FINALIZED — requires physical testing

## Variables
- Diameter
- Thickness
- Shape (round, oval, caplet, capsule)
- Surface friction
- Tendency to bridge or jam
- Coating (smooth vs rough)

## Common Medicine Forms
```
Round tablet      ●     ~8-12mm diameter
Oval tablet       ◉     ~10-15mm long
Caplet            ▬     ~15-20mm long
Capsule          ◯━━◯   ~15-22mm long, ~5-8mm diameter
```

## Design Approach
1. Choose a target medication list from the client
2. Measure the largest tablet/capsule dimensions
3. Size the cylinder inner diameter with 2-3mm clearance
4. Size rotor pockets for the largest expected medicine + tolerance
5. Test with the actual medications

## Known Risks
- Capsules may orient unpredictably in cylinder
- Coated tablets may stick together in humidity
- Very small tablets may double-feed without proper pocket sizing
- Irregular shapes may not feed consistently

## Related
- [[Dispenser Mechanism]]
- [[Module Enclosure]]

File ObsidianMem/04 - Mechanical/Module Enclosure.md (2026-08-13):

# Module Enclosure

## Status: NOT FINALIZED

## Main Module Contains
- ESP32-S3 + ESP32-C3
- USB-C port (accessible)
- Proximity sensor (externally facing)
- Buzzer (audible through enclosure)
- Medicine cylinder + dispenser + hatch + 2 servos
- Power distribution circuitry

## Expansion Module Contains
- Medicine cylinder + dispenser + hatch + 2 servos
- Connector interface (4 wires)

## Design Considerations
- Modules must physically lock together (slide rail / dovetail)
- Medication loading from top (cylinder access)
- Hatch at bottom or side for medicine retrieval
- Ventilation for electronics (if needed)
- Material: 3D printed (prototype), injection molded (production)

## Dimensions
NOT FINALIZED — depends on:
- Cylinder diameter (sized for largest expected tablet)
- Servo model physical size
- PCB dimensions
- Connector placement

## Related
- [[Expansion Concept]]
- [[Connectors]]
- [[Medicine Compatibility]]

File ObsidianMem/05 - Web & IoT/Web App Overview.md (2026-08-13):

# Web App Overview

## Status: Scaffold created

## Architecture
```
Browser → Netlify CDN → Static HTML/CSS/JS
                ↓
         /api/* → Netlify Functions → Database (TBD)
                                ↓
                           ntfy (notifications)
```

## Frontend Pages
| Page | Purpose |
|---|---|
| Dashboard (`index.html`) | Today's schedule, system status |
| Medications (`medications.html`) | CRUD for medications + schedules |
| History (`history.html`) | Dispense event log |
| Settings (`settings.html`) | Device, notifications, modules |

## Backend Functions
| Function | Endpoint | Purpose |
|---|---|---|
| `medications.js` | `/api/medications` | Medication CRUD |
| `schedules.js` | `/api/schedules` | Schedule views |
| `dispense-log.js` | `/api/dispense-log` | Event logging |
| `sync.js` | `/api/sync` | ESP32 schedule sync |
| `notify.js` | `/api/notify` | Server-side ntfy publishing |

## Database
NOT FINALIZED — currently using in-memory stubs.

## Related
- [[API Endpoints]]
- [[Database Schema]]
- [[ntfy Integration]]
- [[Device Sync]]

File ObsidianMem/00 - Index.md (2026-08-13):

# 🗂️ MedBox — Project Knowledge Base

> This Obsidian vault is the persistent memory and knowledge base for the MedBox project.
> Use `[[wikilinks]]` to navigate between notes.

---

## 📋 Sections

### [[01 - Architecture/System Architecture|Architecture]]
- [[01 - Architecture/System Architecture|System Architecture]]
- [[01 - Architecture/Controller Responsibilities|Controller Responsibilities]]
- [[01 - Architecture/Power Architecture|Power Architecture]]
- [[01 - Architecture/Expansion Concept|Expansion Concept]]

### [[02 - Firmware/S3 Firmware Overview|Firmware]]
- [[02 - Firmware/S3 Firmware Overview|S3 Firmware]]
- [[02 - Firmware/C3 Firmware Overview|C3 Firmware]]
- [[02 - Firmware/UART Protocol|UART Protocol]]
- [[02 - Firmware/State Machine|State Machine]]
- [[02 - Firmware/Schedule Storage|Schedule Storage]]

### [[03 - Hardware/GPIO Map|Hardware]]
- [[03 - Hardware/GPIO Map|GPIO Map]]
- [[03 - Hardware/Servo Selection|Servo Selection]]
- [[03 - Hardware/Proximity Sensor|Proximity Sensor]]
- [[03 - Hardware/Connectors|Connectors]]

### [[04 - Mechanical/Dispenser Mechanism|Mechanical]]
- [[04 - Mechanical/Dispenser Mechanism|Dispenser Mechanism]]
- [[04 - Mechanical/Hatch Design|Hatch Design]]
- [[04 - Mechanical/Module Enclosure|Module Enclosure]]
- [[04 - Mechanical/Medicine Compatibility|Medicine Compatibility]]

### [[05 - Web & IoT/Web App Overview|Web & IoT]]
- [[05 - Web & IoT/Web App Overview|Web App]]
- [[05 - Web & IoT/API Endpoints|API Endpoints]]
- [[05 - Web & IoT/Database Schema|Database Schema]]
- [[05 - Web & IoT/ntfy Integration|ntfy Integration]]
- [[05 - Web & IoT/Device Sync|Device Sync]]

### [[06 - Decision Log/Finalized Decisions|Decisions]]
- [[06 - Decision Log/Finalized Decisions|Finalized Decisions]]
- [[06 - Decision Log/Open Questions|Open Questions]]

### Build Log
- Entries added during prototyping in `07 - Build Log/`

---

## 📄 Reference Documents
- Full specification: `../MD Files/MedBox_Final_Project_Specification.md`
- Code architecture: `../MD Files/MedBox_Code_Architecture.md`
- Source code: `../MedDispenser/`

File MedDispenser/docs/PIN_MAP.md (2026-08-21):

# MedBox — Complete Pin Mapping & Interconnect Specification

> **Last Updated:** 2026-08-22 — Pin assignments verified against actual hardware wiring. S3 UART pins corrected to GPIO 1 (TX) / GPIO 2 (RX).

> 📌 **STATUS: FINALIZED & VERIFIED** — Tested against ESP32-S3 SuperMini and ESP32-C3 SuperMini hardware. UART communication confirmed working (PING/PONG/DISPENSE/OPEN/CLOSE).

---

## 1. System Interconnect Summary

```
                    ┌─────────────────────────┐
                    │     USB-C 5V / 3A       │
                    └────────────┬────────────┘
                                 │
                   ┌─────────────┴─────────────┐
                   ▼                           ▼
        ┌─────────────────────┐     ┌─────────────────────┐
        │  5V LOGIC BUS       │     │  5V SERVO RAIL      │
        │ (ESP32-S3 & C3)     │     │ (100-470µF Cap)     │
        └──────────┬──────────┘     └──────────┬──────────┘
                   │                           │
  ┌────────────────┴──────────────┐            │
  │ ESP32-S3 SuperMini (Brain)    │            │
  │  • GPIO 1  (TX)  ─────────────┼──────────┐ │
  │  • GPIO 2  (RX)  ◄────────────┼────────┐ │ │
  │  • GPIO 5  ◄── IR Proximity   │        │ │ │
  │  • GPIO 6  ──► Active Buzzer  │        │ │ │
  └───────────────────────────────┘        │ │ │
                                           │ │ │
  ┌───────────────────────────────┐        │ │ │
  │ ESP32-C3 SuperMini (Motion)   │        │ │ │
  │  • GPIO 20 (RX0) ◄────────────┼────────┘ │ │
  │  • GPIO 21 (TX0) ─────────────┼──────────┘ │
  │  • GPIO 0  ──► M1 Dispenser   │            │
  │  • GPIO 1  ──► M1 Hatch       │            │
  │  • GPIO 3  ──► M2 Dispenser   │            │
  │  • GPIO 4  ──► M2 Hatch       │            │
  │  • GPIO 5  ──► M3 Dispenser   │            │
  │  • GPIO 6  ──► M3 Hatch       │            │
  └───────────────────────────────┘            │
                   │                           │
                   ▼                           ▼
        ┌──────────────────────────────────────────┐
        │ Common GND Bus (Shared System Reference) │
        └──────────────────────────────────────────┘
```

---

## 2. ESP32-S3 SuperMini (Main IoT Controller) Pin Map

| Board Pin Name | GPIO | Function / Peripheral | Physical Connection Target | Signal Direction | Notes |
|:---|:----:|:---|:---|:---:|:---|
| **5V / VBUS** | — | 5V Main Power Input | USB-C 5V Power Rail | Input | Powers board internal 3.3V LDO regulator |
| **3V3** | — | 3.3V Regulated Output | IR Proximity Sensor VCC | Output | Max 300mA total board draw |
| **GND** | — | System Ground | Common GND Bus | Power Ref | **MUST share common ground** with C3 & Servos |
| **GPIO 1** | `GPIO 1` | UART Transmit (TX) | ESP32-C3 `GPIO 20` (RX0) | Output (3.3V) | Transmits ASCII move commands to C3 |
| **GPIO 2** | `GPIO 2` | UART Receive (RX) | ESP32-C3 `GPIO 21` (TX0) | Input (3.3V) | Receives status/ack responses from C3 |
| **GPIO 5** | `GPIO 5` | Proximity / IR Input | IR Obstacle / Proximity Sensor `OUT` | Input (Digital) | Active LOW (configurable via `PROXIMITY_ACTIVE` in `config.h`) |
| **GPIO 6** | `GPIO 6` | Active Buzzer Drive | Active Buzzer `+` terminal | Output (Digital) | Uses `digitalWrite(HIGH/LOW)` — NOT PWM `ledcWrite` |

### ⚠️ ESP32-S3 Strapping Pins (DO NOT USE)
| GPIO | Strapping Function | Risk if Connected |
|:----:|:---|:---|
| `GPIO 0` | Boot Mode (Low = Download, High = SPI Boot) | Boot failure if pulled LOW during startup |
| `GPIO 45` | VDD_SPI Voltage Selector | Can brownout internal SPI flash |
| `GPIO 46` | Boot Log Verbosity / ROM Code | Prevents clean cold boot |

---

## 3. ESP32-C3 SuperMini (Servo Controller) Pin Map

| Board Pin Name | GPIO | Function / Servo Channel | Physical Connection Target | Wire Color | Signal Type |
|:---|:----:|:---|:---|:---:|:---|
| **5V / VBUS** | — | 5V Logic Power | USB-C 5V Power Rail | Red | Power Input |
| **GND** | — | System Ground | Common GND Bus | Black | Common Ground |
| **RX0** | `GPIO 20` | UART0 Receive | ESP32-S3 `GPIO 1` (TX) | Yellow/Blue | Serial RX (115200 Baud) |
| **TX0** | `GPIO 21` | UART0 Transmit | ESP32-S3 `GPIO 2` (RX) | Green/White | Serial TX (115200 Baud) |
| **GPIO 0** | `GPIO 0` | Module 1 Dispenser Servo | M1 Dispenser Servo PWM Signal | Orange/Yellow | PWM (50 Hz, 500-2400 µs) |
| **GPIO 1** | `GPIO 1` | Module 1 Hatch Servo | M1 Hatch Servo PWM Signal | Orange/Yellow | PWM (50 Hz, 500-2400 µs) |
| **GPIO 3** | `GPIO 3` | Module 2 Dispenser Servo | M2 Dispenser Servo PWM Signal | Orange/Yellow | PWM (50 Hz, 500-2400 µs) |
| **GPIO 4** | `GPIO 4` | Module 2 Hatch Servo | M2 Hatch Servo PWM Signal | Orange/Yellow | PWM (50 Hz, 500-2400 µs) |
| **GPIO 5** | `GPIO 5` | Module 3 Dispenser Servo | M3 Dispenser Servo PWM Signal | Orange/Yellow | PWM (50 Hz, 500-2400 µs) |
| **GPIO 6** | `GPIO 6` | Module 3 Hatch Servo | M3 Hatch Servo PWM Signal | Orange/Yellow | PWM (50 Hz, 500-2400 µs) |

### ⚠️ ESP32-C3 Strapping Pins (DO NOT USE)
| GPIO | Strapping Function | Risk if Connected |
|:----:|:---|:---|
| `GPIO 2` | Boot Mode (SPI Boot vs UART Download) | **CRITICAL:** High/Low floating voltage during boot bricks startup |
| `GPIO 8` | Direct Boot State Check | Causes random boot loops |
| `GPIO 9` | Boot Button / Strapping Pin | Internal pull-up; external servo pull down forces boot mode |

---

## 4. Peripherals & Actuators Connection Breakout

### 4.1 Module 1 (Main Box Dispenser & Hatch)
| Device | Pin / Terminal | Connects To | Wire Color Code |
|:---|:---|:---|:---|
| **M1 Dispenser Servo** | Pin 1 (GND) | Common GND Bus | Brown / Black |
| | Pin 2 (VCC) | 5V Dedicated Servo Rail | Red |
| | Pin 3 (Signal) | ESP32-C3 `GPIO 0` | Orange / Yellow |
| **M1 Hatch Servo** | Pin 1 (GND) | Common GND Bus | Brown / Black |
| | Pin 2 (VCC) | 5V Dedicated Servo Rail | Red |
| | Pin 3 (Signal) | ESP32-C3 `GPIO 1` | Orange / Yellow |

### 4.2 Module 2 (Expansion Unit #1)
| Device | Pin / Terminal | Connects To | Wire Color Code |
|:---|:---|:---|:---|
| **M2 Dispenser Servo** | Pin 1 (GND) | Common GND Bus | Brown / Black |
| | Pin 2 (VCC) | 5V Dedicated Servo Rail | Red |
| | Pin 3 (Signal) | ESP32-C3 `GPIO 3` | Orange / Yellow |
| **M2 Hatch Servo** | Pin 1 (GND) | Common GND Bus | Brown / Black |
| | Pin 2 (VCC) | 5V Dedicated Servo Rail | Red |
| | Pin 3 (Signal) | ESP32-C3 `GPIO 4` | Orange / Yellow |

### 4.3 Module 3 (Expansion Unit #2)
| Device | Pin / Terminal | Connects To | Wire Color Code |
|:---|:---|:---|:---|
| **M3 Dispenser Servo** | Pin 1 (GND) | Common GND Bus | Brown / Black |
| | Pin 2 (VCC) | 5V Dedicated Servo Rail | Red |
| | Pin 3 (Signal) | ESP32-C3 `GPIO 5` | Orange / Yellow |
| **M3 Hatch Servo** | Pin 1 (GND) | Common GND Bus | Brown / Black |
| | Pin 2 (VCC) | 5V Dedicated Servo Rail | Red |
| | Pin 3 (Signal) | ESP32-C3 `GPIO 6` | Orange / Yellow |

### 4.4 Proximity Sensor & Buzzer
| Component | Sensor Pin | Connects To | Notes |
|:---|:---|:---|:---|
| **IR Proximity Sensor** | VCC | ESP32-S3 `3V3` Pin | Or 5V depending on module model (e.g. FC-51) |
| | GND | Common GND Bus | Shared Ground |
| | OUT / DO | ESP32-S3 `GPIO 5` | Digital Input |
| **Active Buzzer** | Positive (`+`) | ESP32-S3 `GPIO 6` | Direct `digitalWrite(HIGH/LOW)` — NOT PWM |
| | Negative (`-`) | Common GND Bus | Shared Ground |

---

## 5. Expansion Module Interconnect Bus (4-Pin Connector)

Each expansion module connects to the main controller chassis via a standardized 4-pin plug/socket (e.g. JST-XH 2.54mm or Header Pins):

```
Expansion Bus Connector (Female Header on Main Unit / Male Plug on Expansion Module):
┌──────────────────────────────────────────┐
│  [1] +5V_SERVO  │  (Red)     ──► Servo Power Rail (5V 3A)
│  [2] GND        │  (Black)   ──► Common System Ground
│  [3] DISP_PWM   │  (Yellow)  ──► ESP32-C3 GPIO (3 or 5)
│  [4] HATCH_PWM  │  (White)   ──► ESP32-C3 GPIO (4 or 6)
└──────────────────────────────────────────┘
```

---

## 6. Power Distribution Wiring & Filtering Rules

1. **Dedicated Servo Rail:** Never feed motor supply power through the 3.3V or 5V output pin of either ESP32 board. Wire servo VCC directly to the main 5V power bus.
2. **Decoupling Capacitor:** Solder a **470 µF / 16V Low-ESR Electrolytic Capacitor** across the 5V Servo Rail and GND near the servo connectors to absorb current surges during motor start.
3. **Common Ground:** All GND pins from the power supply, ESP32-S3, ESP32-C3, proximity sensor, buzzer, and all 6 servos **MUST BE CONNECTED TOGETHER** to establish a zero-volt logic reference.

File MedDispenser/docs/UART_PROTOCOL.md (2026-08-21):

# MedBox — UART Protocol Specification

> **Last Updated:** 2026-08-22 — Added extended `DISPENSE,N,count` format for multi-pill dosing.

## Physical Layer
- **Interface**: UART (Hardware Serial)
- **Baud rate**: 115200
- **Data format**: 8N1
- **Wiring**: S3 TX (GPIO 1) → C3 RX (GPIO 20), S3 RX (GPIO 2) ← C3 TX (GPIO 21), common GND

### ESP32-C3 Silicon Constraint

The ESP32-C3 has **only 1 UART peripheral** (`UART0`). Using `HardwareSerial(1)` fails silently. The firmware uses `HardwareSerial SerialS3(0)` on pins 20 & 21 with **USB CDC On Boot = Enabled** in Arduino IDE board settings, keeping USB debug output functional alongside UART communication.

## Message Format

### Commands (S3 → C3)
```
CMD,<module_id>\n
CMD,<module_id>,<extra_value>\n
```

### Responses (C3 → S3)
```
OK,CMD,<module_id>\n
ERR,CMD,<module_id>,<error_code>\n
PONG\n
```

## Command Reference

| Command | Description | Example |
|---|---|---|
| `DISPENSE,N` | Dispense 1 pill from module N (default count=1) | `DISPENSE,1\n` |
| `DISPENSE,N,C` | Dispense C pills from module N (C revolutions) | `DISPENSE,1,3\n` |
| `OPEN,N` | Open hatch on module N (90°) | `OPEN,1\n` |
| `CLOSE,N` | Close hatch on module N (0°) | `CLOSE,1\n` |
| `HOME,N` | Return module N dispenser to home position | `HOME,1\n` |
| `STATUS,N` | Query servo status of module N | `STATUS,3\n` |
| `PING,0` | Connection check (heartbeat) | `PING,0\n` |

### Extended Format: `DISPENSE,N,C`

The `uartSendCommandEx()` function on the S3 sends multi-parameter messages. The C3's `uart_handler.cpp` parses the optional third field:

```
DISPENSE,1,2\n   →  Module 1, dispense 2 pills (2 full 360° revolutions)
DISPENSE,1\n     →  Module 1, dispense 1 pill (default)
```

## Response Examples

| Response | Meaning |
|---|---|
| `OK,DISPENSE,1` | Module 1 dispense completed |
| `OK,OPEN,2` | Module 2 hatch opened |
| `ERR,DISPENSE,4,2` | Error: module 4 is invalid (error code 2) |
| `PONG` | Heartbeat response |

## Error Codes

| Code | Name | Meaning |
|---|---|---|
| 1 | `ERR_UNKNOWN_CMD` | Unrecognized command |
| 2 | `ERR_INVALID_MODULE` | Module ID out of range (1-3) |
| 3 | `ERR_SERVO_FAULT` | Servo did not reach target (future) |
| 4 | `ERR_BUSY` | Another operation in progress |
| 5 | `ERR_PARSE` | Malformed message |

## Timing
- **Timeout**: 2000 ms max wait for response
- **Max message length**: 64 bytes
- **Delimiter**: `,` (comma)
- **Terminator**: `\n` (newline)

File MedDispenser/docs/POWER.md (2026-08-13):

# MedBox — Power Architecture

## Topology

```
USB-C INPUT (5V)
      │
  Protection (reverse polarity, overcurrent, ESD)
      │
  5V MAIN BUS
      │
  ┌───┴────────────────┐
  │                    │
  ▼                    ▼
LOGIC POWER        SERVO POWER RAIL
  │                    │
  ├── ESP32-S3         ├── Module 1 Dispenser Servo
  ├── ESP32-C3         ├── Module 1 Hatch Servo
  ├── Proximity Sensor ├── Module 2 Dispenser Servo
  └── Buzzer           ├── Module 2 Hatch Servo
                       ├── Module 3 Dispenser Servo
                       └── Module 3 Hatch Servo
```

## Current Budget (Estimated)

> ⚠️ Exact values depend on servo model (NOT FINALIZED)

| Component | Typical Current | Peak Current |
|---|---|---|
| ESP32-S3 (Wi-Fi active) | ~150 mA | ~350 mA |
| ESP32-C3 | ~80 mA | ~150 mA |
| Proximity sensor | ~20 mA | ~30 mA |
| Buzzer | ~30 mA | ~50 mA |
| **Logic subtotal** | **~280 mA** | **~580 mA** |
| | | |
| SG90-class servo (idle) | ~10 mA | — |
| SG90-class servo (moving) | ~200 mA | ~500 mA |
| **Per module (2 servos)** | **~20 mA idle** | **~1000 mA peak** |
| | | |
| **Worst case (3 modules, 2 moving)** | — | **~1580 mA** |

## Power Supply Recommendation

- Minimum: **5V 2A** USB-C charger (for 1-2 module prototype)
- Recommended: **5V 3A** for 3-module system with margin
- Servo operations should be sequenced (not all at once) to reduce peak draw

## Protection Considerations

| Protection | Purpose | Implementation |
|---|---|---|
| Reverse polarity | Prevent damage from miswired supply | Schottky diode or P-MOSFET circuit |
| Overcurrent | Protect wiring/PCB traces | Resettable fuse (PTC) on servo rail |
| Transient/ESD | Protect USB-C port | TVS diode on VBUS |
| Bulk capacitance | Smooth servo current spikes | 100–470 µF electrolytic near servo rail |
| Decoupling | Clean logic power | 100 nF ceramic near each ESP32 |

## Key Rule
> Servos are powered from the dedicated 5V servo rail, NOT through the ESP32's 5V pin.

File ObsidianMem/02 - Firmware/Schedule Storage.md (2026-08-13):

# Schedule Storage

## Status: Implemented (firmware scaffold)

## Storage Method
ESP32 NVS (Non-Volatile Storage) via `Preferences` library.

## Data Structure
```cpp
struct MedSchedule {
  bool     active;
  uint8_t  moduleId;          // 1-3
  char     medicineName[32];
  uint8_t  pillsPerDose;
  uint8_t  hour;              // 0-23
  uint8_t  minute;            // 0-59
  uint8_t  daysOfWeek;        // Bitmask: bit0=Sun, bit6=Sat
  uint32_t startDate;         // Epoch or 0
  uint32_t endDate;           // Epoch or 0
  bool     enabled;
};
```

## Capacity
- `MAX_SCHEDULES = 16`
- NVS namespace: `"medbox"`

## Sync Flow
1. ESP32 calls `GET /api/sync` periodically
2. Receives JSON array of schedules
3. `scheduleClearAll()` + `scheduleAdd()` for each
4. `scheduleSaveToNVS()` persists to flash

## Day-of-Week Bitmask
| Bit | Day |
|-----|-----|
| 0 | Sunday |
| 1 | Monday |
| 2 | Tuesday |
| 3 | Wednesday |
| 4 | Thursday |
| 5 | Friday |
| 6 | Saturday |

Example: Mon-Fri = `0b0111110` = 62

## Related
- [[S3 Firmware Overview]]
- [[Device Sync]]

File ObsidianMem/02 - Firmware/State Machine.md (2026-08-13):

# State Machine

## Status: FINALIZED (states), firmware implemented

## States
1. **IDLE** — waiting for a schedule to trigger
2. **REMINDER** — buzzer + ntfy notification sent
3. **WAITING_FOR_USER** — polling proximity, re-reminding every 5 min
4. **HATCH_OPENING** — UART OPEN command to C3
5. **DISPENSING** — UART DISPENSE command to C3
6. **USER_TAKING_MEDICINE** — hatch open, waiting for user
7. **HATCH_CLOSING** — UART CLOSE command to C3
8. **COMPLETED** — event logged, return to IDLE
9. **ERROR** — recovers to IDLE after timeout

## Key Behaviors
- Re-reminder every `REMINDER_INTERVAL_MS` (5 min default)
- Max `REMINDER_MAX_RETRIES` (12 default = 1 hour) before logging missed dose
- Proximity must be confirmed before hatch opens
- Hatch stays open for `HATCH_OPEN_WAIT_MS` (15 sec default)

## Implementation
File: `medbox_s3/state_machine.cpp`

## Related
- [[S3 Firmware Overview]]
- [[UART Protocol]]

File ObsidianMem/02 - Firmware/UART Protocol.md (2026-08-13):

# UART Protocol

## Status: FINALIZED (format), NOT FINALIZED (error handling details)

## Physical
- UART, 115200 baud, 8N1
- S3 TX → C3 RX, S3 RX ← C3 TX, common GND

## Format
```
Command:  CMD,moduleId\n
Response: OK,CMD,moduleId\n
Error:    ERR,CMD,moduleId,errorCode\n
```

## Commands
| Command | Description |
|---|---|
| `DISPENSE,N` | Dispense one dose from module N |
| `OPEN,N` | Open hatch N |
| `CLOSE,N` | Close hatch N |
| `HOME,N` | Return module N to home |
| `STATUS,N` | Query module N status |
| `PING,0` | Heartbeat check |

## Error Codes
| Code | Name |
|---|---|
| 1 | Unknown command |
| 2 | Invalid module |
| 3 | Servo fault (future) |
| 4 | Busy |
| 5 | Parse error |

## Timing
- Timeout: 2000 ms
- Max message: 64 bytes

## Related
- [[S3 Firmware Overview]]
- [[C3 Firmware Overview]]

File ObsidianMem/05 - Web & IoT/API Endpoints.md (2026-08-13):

# API Endpoints

## Base URL
Production: `https://your-medbox-app.netlify.app/api/`
Local dev: `http://localhost:8888/api/`

## Endpoints

### Medications
| Method | Path | Description |
|---|---|---|
| GET | `/api/medications` | List all medications |
| POST | `/api/medications` | Create medication |
| PUT | `/api/medications/:id` | Update medication |
| DELETE | `/api/medications/:id` | Delete medication |

### Schedules
| Method | Path | Description |
|---|---|---|
| GET | `/api/schedules` | Get all schedules |
| GET | `/api/schedules?today=true` | Get today's schedules |

### Dispense Log
| Method | Path | Description |
|---|---|---|
| GET | `/api/dispense-log?limit=50` | Get recent logs |
| POST | `/api/dispense-log` | Record dispense event |

### Device Sync
| Method | Path | Description |
|---|---|---|
| GET | `/api/sync` | Get ESP32 schedule payload |

### Notifications
| Method | Path | Description |
|---|---|---|
| POST | `/api/notify` | Publish ntfy notification |

## Related
- [[Web App Overview]]
- [[Database Schema]]
- [[Device Sync]]

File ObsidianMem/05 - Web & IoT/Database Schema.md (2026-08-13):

# Database Schema

## Status: NOT FINALIZED (database provider TBD)

## Proposed Tables

### PATIENT
| Field | Type | Notes |
|---|---|---|
| id | string/UUID | Primary key |
| name | string | Patient name |
| notification_topic | string | ntfy topic |
| created_at | timestamp | |

### MEDICATION
| Field | Type | Notes |
|---|---|---|
| id | string/UUID | Primary key |
| patient_id | string | FK → Patient |
| name | string | Medicine name |
| module_id | int | 1-3 |
| pills_per_dose | int | Tablets per intake |
| time | string | "HH:MM" |
| days_of_week | int | Bitmask (bit0=Sun) |
| start_date | date | Optional |
| end_date | date | Optional |
| enabled | bool | Active/disabled |
| active | bool | Soft delete |

### DISPENSE_LOG
| Field | Type | Notes |
|---|---|---|
| id | string/UUID | Primary key |
| medication_id | string | FK → Medication |
| module_id | int | Module that dispensed |
| scheduled_time | timestamp | When it was scheduled |
| actual_time | timestamp | When it actually dispensed |
| requested_quantity | int | Pills requested |
| status | string | dispensed/missed/error |
| error | string | Error message if any |

## Database Candidates
- Supabase (PostgreSQL)
- MongoDB Atlas
- PlanetScale / Turso (serverless SQL)
- Netlify Blobs (simple, limited)

## Related
- [[API Endpoints]]
- [[Web App Overview]]

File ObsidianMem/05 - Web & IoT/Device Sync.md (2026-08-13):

# Device Sync

## Status: Scaffold implemented

## Sync Flow
```
ESP32-S3 (periodic, every 5 min)
     ↓
GET /api/sync
     ↓
Backend returns JSON schedule array
     ↓
ESP32 parses → clears old → adds new → saves to NVS
```

## Sync Payload Format (Backend → ESP32)
```json
{
  "serverTime": 1723593600,
  "schedules": [
    {
      "moduleId": 1,
      "medicineName": "Metformin",
      "pillsPerDose": 1,
      "hour": 7,
      "minute": 0,
      "daysOfWeek": 62,
      "startDate": 0,
      "endDate": 0,
      "enabled": true
    }
  ]
}
```

## Offline Behavior
- If sync fails, device continues using last saved schedule
- Schedules are persisted in NVS (flash memory)
- Device does **not** depend on Internet at dispensing time

## Sync Interval
- Default: `API_SYNC_INTERVAL_MS = 300000` (5 minutes)
- Can be adjusted in `config.h`

## Related
- [[Schedule Storage]]
- [[API Endpoints]]
- [[S3 Firmware Overview]]

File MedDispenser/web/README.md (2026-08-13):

# MedBox — Web Application

## Structure

```
web/
├── frontend/           Static HTML/CSS/JS (deployed to Netlify)
│   ├── index.html      Dashboard
│   ├── medications.html Medication CRUD
│   ├── history.html    Dispense history
│   ├── settings.html   System settings
│   ├── css/style.css   Design system
│   └── js/             Client-side logic
│
├── netlify/
│   ├── functions/      Serverless API functions
│   └── ...
│
└── netlify.toml        Netlify config & API redirects
```

## Architecture

```
Browser → Netlify CDN → Static Frontend
                ↓
        /api/* routes → Netlify Functions → Database
                                    ↓
                               ntfy (notifications)
                                    ↓
                               ESP32 (sync endpoint)
```

## Deployment
1. Connect the `web/` directory to a Netlify site.
2. Set environment variables in the Netlify dashboard.
3. Deploy — frontend and functions are deployed together.

## Local Development
```bash
cd web
npx netlify-cli dev
```

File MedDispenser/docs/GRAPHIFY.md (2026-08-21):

# MedBox — Graphify Knowledge Graph Setup & Usage

> **Last Updated:** 2026-08-22 — Initial setup of Graphify for AI codebase token management.

---

## What is Graphify?

[Graphify](https://github.com/closedloop-technologies/graphifyy) is an AI codebase analysis tool that uses **Tree-sitter** (local AST parsing) to create a structured knowledge graph of your project. It helps AI coding assistants (Claude, Cursor, Copilot, etc.) navigate your codebase efficiently by providing a dependency map instead of re-reading raw files — **drastically reducing token consumption**.

- **No cloud upload** — all parsing is done locally via deterministic AST analysis
- **No API cost** — `graphify update .` runs entirely offline
- **Supports C/C++, JavaScript, HTML, JSON, and 20+ languages**

---

## Installation

Graphify was installed via pip:

```bash
pip install graphifyy
```

**Executable location:**
```
C:\Users\Jan Clyde Talosig\AppData\Roaming\Python\Python314\Scripts\graphify.exe
```

**Agent integration installed via:**
```bash
graphify install
```

This created:
- Skill file: `C:\Users\Jan Clyde Talosig\.claude\skills\graphify\SKILL.md`
- Config: `C:\Users\Jan Clyde Talosig\.claude\CLAUDE.md`

---

## Output Directory

All graphify output is stored in `graphify-out/` at the project root:

```
MedDispenser/
└── graphify-out/
    ├── graph.json          # Machine-readable knowledge graph (315 KB)
    ├── graph.html          # Interactive visual explorer (open in browser)
    ├── GRAPH_REPORT.md     # Summary report (god nodes, communities, gaps)
    ├── manifest.json       # File manifest with metadata
    ├── .graphify_root      # Root marker
    ├── .graphify_labels.json
    └── cache/              # Internal cache (gitignored)
```

---

## Current Graph Statistics

| Metric | Value |
|---|---|
| **Files Analyzed** | 57 files |
| **Word Count** | ~94,616 words |
| **Nodes** | 337 |
| **Edges** | 463 |
| **Communities** | 36 (28 shown, 8 thin omitted) |
| **Extraction** | 89% EXTRACTED, 11% INFERRED, 0% AMBIGUOUS |
| **Built from Commit** | `d22ebba7` |

---

## God Nodes (Most Connected — Core Abstractions)

These are the most interconnected functions/files in your codebase. Changes here have the widest ripple effect:

| Rank | Node | Edges | File |
|---|---|---|---|
| 1 | `stateMachineUpdate()` | 11 | `firmware/medbox_s3/state_machine.cpp` |
| 2 | `DEVICE_OPERATION_GUIDE.md` | 11 | `docs/DEVICE_OPERATION_GUIDE.md` |
| 3 | `apiClientSyncSchedules()` | 9 | `firmware/medbox_s3/api_client.cpp` |
| 4 | `_processCommand()` | 8 | `firmware/medbox_c3/uart_handler.cpp` |
| 5 | `_beginHttp()` | 8 | `firmware/medbox_s3/api_client.cpp` |
| 6 | `apiClientUpdate()` | 8 | `firmware/medbox_s3/api_client.cpp` |
| 7 | `_getTime()` | 8 | `firmware/medbox_s3/time_manager.cpp` |
| 8 | `wifiIsConnected()` | 8 | `firmware/medbox_s3/wifi_manager.cpp` |
| 9 | `ARCHITECTURE.md` | 8 | `docs/ARCHITECTURE.md` |
| 10 | `wifiManagerInit()` | 7 | `firmware/medbox_s3/wifi_manager.cpp` |

---

## Community Breakdown (Key Clusters)

| Community | Hub | Cohesion | Nodes | Description |
|---|-----|---|---|---|
| 0 | `api_client.cpp` | 0.08 | 28 | HTTP sync, command polling, heartbeat, notifications |
| 1 | `time_manager.cpp` | 0.16 | 19 | NTP sync, schedule evaluation, time functions |
| 2 | `wifi_manager.cpp` | 0.16 | 20 | Wi-Fi provisioning, captive portal, NVS credentials |
| 3 | `servo_controller.cpp` | 0.17 | 12 | Servo PWM control, dispense/hatch/home commands |
| 4 | `DEVICE_OPERATION_GUIDE.md` | 0.11 | 18 | Main documentation hub |
| 5 | `PIN_MAP.md` | 0.14 | 13 | Hardware wiring documentation |
| 6 | `data/app.js` | 0.25 | 11 | Wi-Fi captive portal frontend |
| 9 | `js/app.js` | 0.33 | 9 | Dashboard, schedule checker, device rendering |
| 10 | `buzzer.cpp` | 0.39 | 7 | Buzzer tone patterns |
| 12 | `js/medications.js` | 0.39 | 7 | Medication CRUD UI |

---

## Surprising Connections (Cross-Module Dependencies)

These are inferred connections the graph discovered that may not be immediately obvious:

| Source | → Target | Via |
|---|---|-----|
| `apiClientUpdate()` | `buzzerPatternStart()` | `api_client.cpp` → `buzzer.cpp` |
| `apiClientSyncSchedules()` | `scheduleAdd()` | `api_client.cpp` → `schedule_manager.cpp` |
| `apiClientSyncSchedules()` | `scheduleClearAll()` | `api_client.cpp` → `schedule_manager.cpp` |
| `apiClientSyncSchedules()` | `scheduleSaveToNVS()` | `api_client.cpp` → `schedule_manager.cpp` |
| `apiClientSyncSchedules()` | `timeSetEpoch()` | `api_client.cpp` → `time_manager.cpp` |

---

## How to Use Graphify

### Update the Graph (After Code Changes)
```bash
# From project root
graphify update .
```
This re-parses your codebase and rebuilds the knowledge graph. No API cost, runs 100% locally.

### Explore Visually
Open `graphify-out/graph.html` in your browser to interactively explore the knowledge graph with a force-directed node visualization.

### Query the Graph (Inside AI Assistants)
```
/graphify query "What breaks if I change stateMachineUpdate()?"
/graphify path "api_client.cpp" "servo_controller.cpp"
/graphify explain "apiClientSyncSchedules"
```

### Check Graph Freshness
```bash
git rev-parse HEAD
# Compare with "Built from commit" in GRAPH_REPORT.md
```

---

## Knowledge Gaps

The graph identified **92 isolated nodes** with ≤1 connection. These are likely:
- Frontend API wrapper functions (e.g., `Api.*` calls)
- Local variables and constants (e.g., `_triggeredSchedules`, `HW_COMMAND_LABELS`)
- These are normal for a mixed firmware + web project

---

## Integration Points

| AI Tool | Integration Method |
|---|---|
| Claude Code | Skill installed at `~/.claude/skills/graphify/SKILL.md` |
| Cursor | Add `graphify-out/GRAPH_REPORT.md` to context |
| Other Assistants | Point to `graphify-out/graph.json` as project map |

---

## File Locations

| File | Path |
|---|---|
| Graphify executable | `C:\Users\Jan Clyde Talosig\AppData\Roaming\Python\Python314\Scripts\graphify.exe` |
| Knowledge graph | `MedDispenser/graphify-out/graph.json` |
| Visual explorer | `MedDispenser/graphify-out/graph.html` |
| Graph report | `MedDispenser/graphify-out/GRAPH_REPORT.md` |
| Agent skill | `C:\Users\Jan Clyde Talosig\.claude\skills\graphify\SKILL.md` |

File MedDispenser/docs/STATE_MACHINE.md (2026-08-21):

# MedBox — Firmware State Machine

> **Last Updated:** 2026-08-22 — Reflects IR-gated hatch opening & dispense-first flow.

## States

```cpp
enum SystemState {
    STATE_IDLE,
    STATE_REMINDER,
    STATE_DISPENSING,
    STATE_WAITING_FOR_USER,
    STATE_HATCH_OPENING,
    STATE_USER_TAKING_MEDICINE,
    STATE_HATCH_CLOSING,
    STATE_COMPLETED,
    STATE_ERROR
};
```

## State Transition Diagram

```
                    ┌──────────────────────────────────────┐
                    │                                      │
                    ▼                                      │
              ┌──────────┐                                 │
              │   IDLE   │◄────────────────────────────────┤
              └────┬─────┘                                 │
                   │ schedule pending                      │
                   ▼                                       │
              ┌──────────┐                                 │
              │ REMINDER │ buzzer + ntfy push              │
              └────┬─────┘                                 │
                   │ immediately                           │
                   ▼                                       │
         ┌─────────────────────┐                           │
         │    DISPENSING        │ UART: DISPENSE,N,count    │
         │                     │ (hatch stays CLOSED)      │
         │ Spins 360° × count  │                           │
         └────────┬────────────┘                           │
                  │ pill(s) dropped into compartment       │
                  ▼                                        │
         ┌─────────────────────┐                           │
         │ WAITING_FOR_USER    │                           │
         │                     │──── max retries ──────────┘
         │ Hatch CLOSED (0°)   │     → log missed dose
         │ Re-remind buzzer    │
         │  every 5 min        │
         └────────┬────────────┘
                  │ 🔴 IR proximity sensor DETECTED
                  ▼
         ┌─────────────────────┐
         │   HATCH_OPENING     │ UART: OPEN,N → 90°
         └────────┬────────────┘
                  │ 1s delay
                  ▼
         ┌─────────────────────┐
         │ USER_TAKING_MEDICINE│ Hatch OPEN for 5 seconds
         └────────┬────────────┘
                  │ timeout
                  ▼
         ┌─────────────────────┐
         │   HATCH_CLOSING     │ UART: CLOSE,N → 0°
         └────────┬────────────┘
                  │ 1s delay
                  ▼
         ┌─────────────────────┐
         │    COMPLETED        │ log event → IDLE
         └────────────────────┘
```

## Dispensing Sequence Detail

1. **REMINDER** — Buzzer alarm (3 beeps × 500ms) + ntfy push notification sent to phone
2. **DISPENSING** — Dispenser servo spins `pillsPerDose` × 360° revolutions behind **closed** hatch; pill(s) drop into internal staging compartment
3. **WAITING_FOR_USER** — Hatch remains sealed at 0°. System waits for user to place hand near IR sensor. Buzzer re-reminds every 5 minutes. After 12 retries (1 hour), logs as "missed dose"
4. **HATCH_OPENING** — Only triggered when `proximityIsDetected() == true`. Sends `OPEN` command → hatch rotates to 90°
5. **USER_TAKING_MEDICINE** — Hatch stays open for 5 seconds for user to retrieve pill
6. **HATCH_CLOSING** — Sends `CLOSE` command → hatch rotates back to 0°
7. **COMPLETED** — Logs "dispensed" to backend, marks schedule handled, returns to IDLE

## UART Command Spam Prevention

The state machine runs inside `loop()` at ~1000 iterations/second. A `_cmdSentInState` flag ensures each UART command (`DISPENSE`, `OPEN`, `CLOSE`) is sent **exactly once** per state entry. The flag resets automatically in `_enterState()`.

## Error State
- Entered on servo communication failure, timeout, or invalid state
- Recovers to IDLE after 5 seconds
- Should log the error for backend reporting

## Timing Constants

| Parameter | Default | Config Key |
|---|---|---|
| Reminder interval | 5 min | `REMINDER_INTERVAL_MS` |
| Max reminders | 12 | `REMINDER_MAX_RETRIES` |
| Buzzer pattern | 3 beeps × 500ms | `BUZZER_PATTERN_COUNT` |
| Dispenser rev time | 2.4s per pill | `DISPENSER_REV_TIME_MS` |
| S3 wait per pill | 3s per pill + 0.5s | Calculated in state machine |
| Hatch open duration | 5s | Hardcoded in `STATE_USER_TAKING_MEDICINE` |
| Hatch servo delay | 1s | Hardcoded in `STATE_HATCH_OPENING/CLOSING` |

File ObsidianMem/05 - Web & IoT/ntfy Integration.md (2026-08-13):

# ntfy Integration

## Status: FINALIZED (concept), scaffold implemented

## Architecture
```
Medication event
     ↓
Backend (Netlify Function)
     ↓
ntfy API (server-side publish)
     ↓
User's phone (push notification)
```

## Security
- ntfy credentials stored as Netlify environment variables
- **Never** exposed in frontend JavaScript
- Publishing done server-side via `notify.js` function

## Environment Variables
| Variable | Description |
|---|---|
| `NTFY_TOPIC` | Topic name (e.g., "medbox-user123") |
| `NTFY_SERVER` | Server URL (default: `https://ntfy.sh`) |
| `NTFY_TOKEN` | Optional auth token for private topics |

## Notification Format
```
Title: 💊 Medication Reminder
Body:
  Medicine: Metformin
  Dose: 1 tablet(s)
  Time: 07:00
  Module: 1

  Please take your scheduled medication.
```

## Trigger Points
1. Schedule time reached → reminder notification
2. Max retries exceeded → missed dose notification
3. System error → alert notification (future)

## Related
- [[Web App Overview]]
- [[State Machine]]

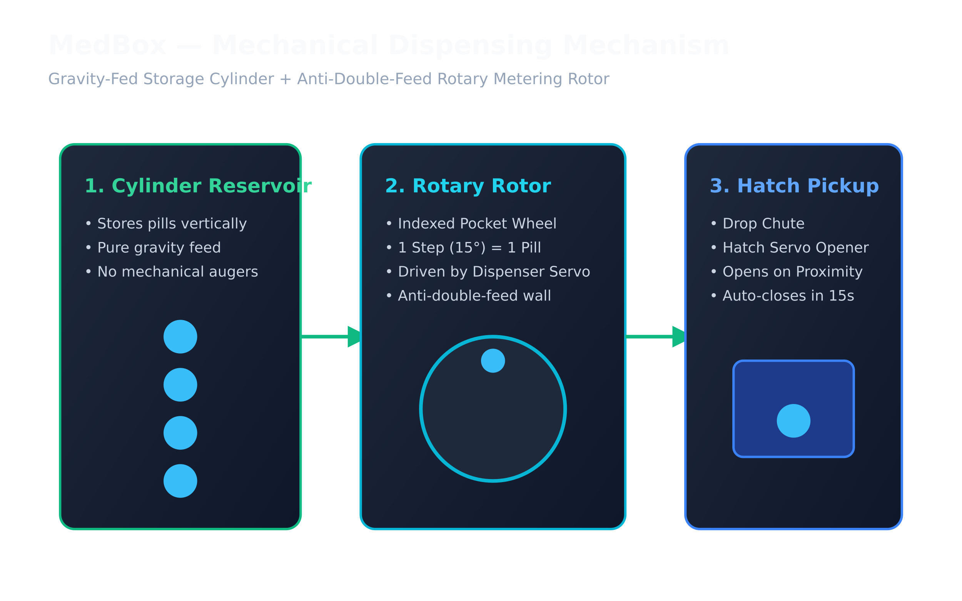
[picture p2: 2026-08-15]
MedDispenser/docs/diagrams/6_mechanical_dispensing.jpg

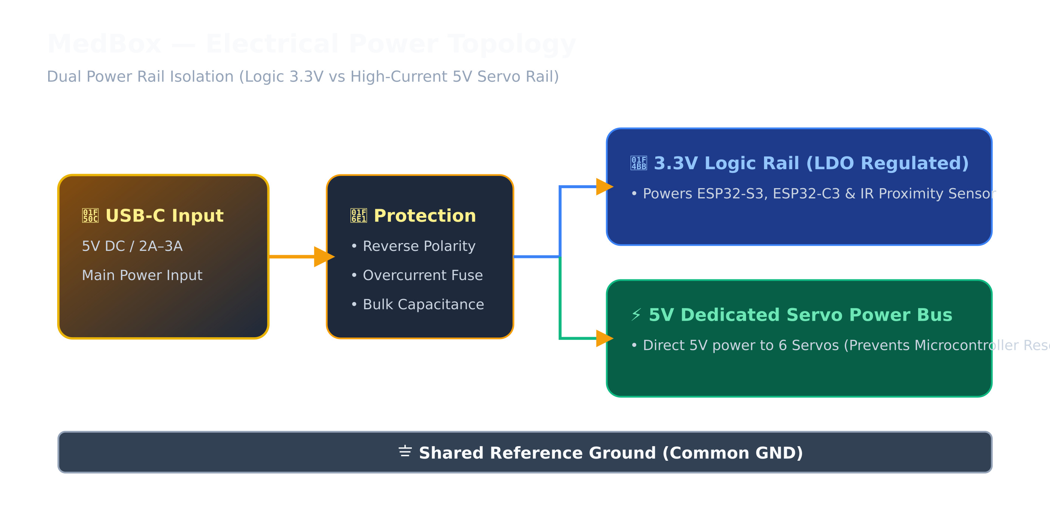
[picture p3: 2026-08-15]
MedDispenser/docs/diagrams/3_electrical_power_topology.jpg

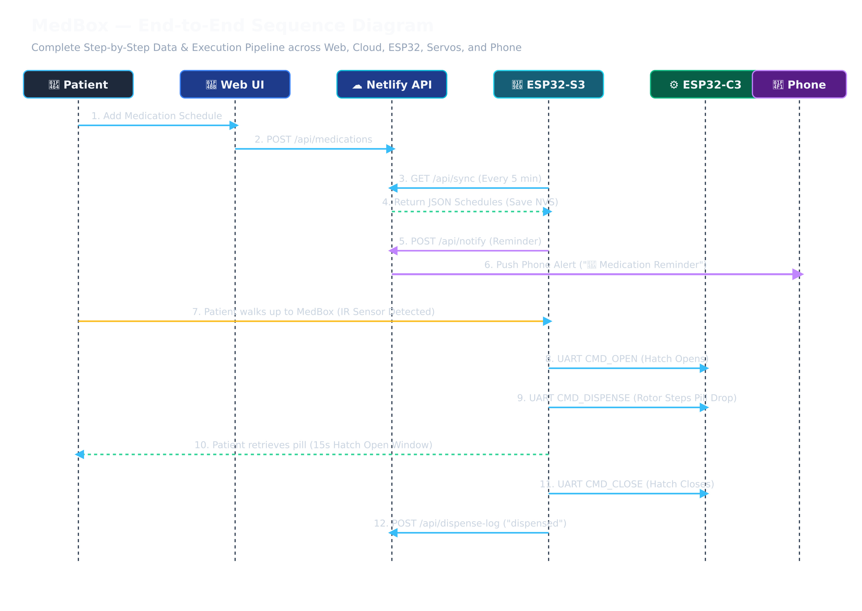
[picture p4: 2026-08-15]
MedDispenser/docs/diagrams/5_end_to_end_sequence.jpg

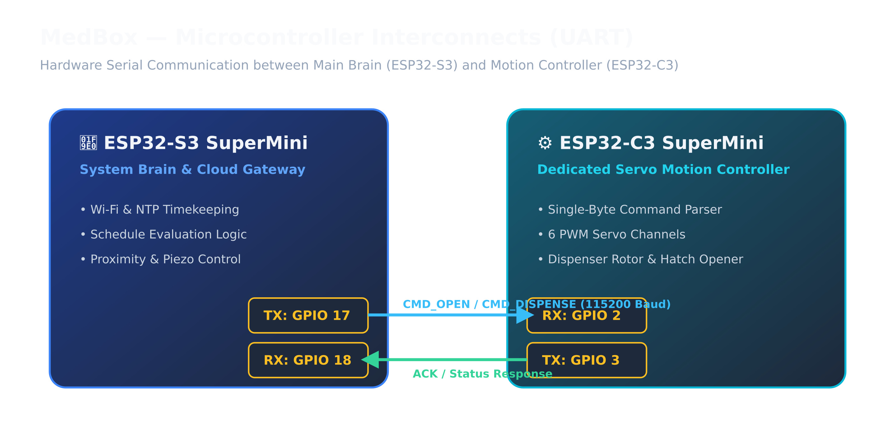
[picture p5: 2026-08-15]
MedDispenser/docs/diagrams/2_microcontroller_interconnects.jpg

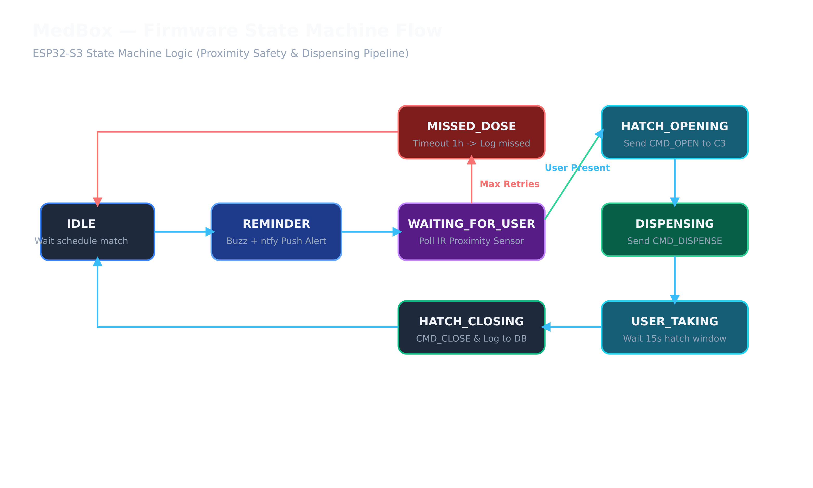
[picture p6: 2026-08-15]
MedDispenser/docs/diagrams/4_firmware_state_machine.jpg

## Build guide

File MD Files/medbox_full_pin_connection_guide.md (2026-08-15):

# MedBox — Complete Pin Connection & Wiring Guide

This guide provides the definitive, complete pin connection mapping and hardware wiring instructions for the **MedBox Modular Smart Medication Dispenser**. It covers the dual-microcontroller architecture (ESP32-S3 SuperMini & ESP32-C3 SuperMini), sensors, audio indicators, power distribution rails, and all 6 servo actuators (Modules 1, 2, and 3).

---

## 1. High-Level Hardware Architecture & Interconnect Map

```mermaid
flowchart TB
    subgraph Power["🔌 Power Supply Infrastructure"]
        USBC["USB-C 5V Input (5V / 2A-3A)"]
        FUSE["Resettable Fuse (PTC) & Reverse Diode"]
        LOGIC_BUS["⚡ 5V Logic Bus"]
        SERVO_BUS["🔋 5V Dedicated Servo Rail<br/>(With 470µF 16V Capacitor)"]
        GND_BUS["⏚ Common System Ground Bus"]

        USBC --> FUSE
        FUSE --> LOGIC_BUS & SERVO_BUS
    end

    subgraph S3_Brain["🧠 ESP32-S3 SuperMini (Main IoT Brain)"]
        S3_5V["5V / VBUS Pin"]
        S3_GND["GND Pin"]
        S3_TX["GPIO 17 (UART1 TX)"]
        S3_RX["GPIO 18 (UART1 RX)"]
        S3_PROX["GPIO 5 (Digital IN)"]
        S3_BUZZ["GPIO 6 (PWM OUT)"]
    end

    subgraph C3_Motion["⚙️ ESP32-C3 SuperMini (Servo Controller)"]
        C3_5V["5V / VBUS Pin"]
        C3_GND["GND Pin"]
        C3_RX["GPIO 20 (UART0 RX)"]
        C3_TX["GPIO 21 (UART0 TX)"]
        
        M1_DISP_PIN["GPIO 0 (M1 Dispenser PWM)"]
        M1_HATCH_PIN["GPIO 1 (M1 Hatch PWM)"]
        M2_DISP_PIN["GPIO 3 (M2 Dispenser PWM)"]
        M2_HATCH_PIN["GPIO 4 (M2 Hatch PWM)"]
        M3_DISP_PIN["GPIO 5 (M3 Dispenser PWM)"]
        M3_HATCH_PIN["GPIO 6 (M3 Hatch PWM)"]
    end

    subgraph Peripherals["🔔 Sensors & Indicators"]
        IR_SENS["IR Proximity / Presence Sensor"]
        BUZZER["Piezo Electric Buzzer"]
    end

    subgraph Actuators["🦾 Servo Actuators (Module 1 - 3)"]
        M1_DISP["Module 1 Dispenser Servo"]
        M1_HATCH["Module 1 Hatch Servo"]
        M2_DISP["Module 2 Dispenser Servo"]
        M2_HATCH["Module 2 Hatch Servo"]
        M3_DISP["Module 3 Dispenser Servo"]
        M3_HATCH["Module 3 Hatch Servo"]
    end

    %% Power Wiring
    LOGIC_BUS ==> S3_5V & C3_5V & IR_SENS
    SERVO_BUS ==> M1_DISP & M1_HATCH & M2_DISP & M2_HATCH & M3_DISP & M3_HATCH
    GND_BUS === S3_GND & C3_GND & IR_SENS & BUZZER & M1_DISP & M1_HATCH & M2_DISP & M2_HATCH & M3_DISP & M3_HATCH

    %% Signal Wiring
    S3_TX --->|"Serial Commands"| C3_RX
    C3_TX --->|"Status / ACK"| S3_RX
    IR_SENS --->|"Presence Detect"| S3_PROX
    S3_BUZZ --->|"Beep Tone"| BUZZER

    %% Servo Signals
    M1_DISP_PIN ---> M1_DISP
    M1_HATCH_PIN ---> M1_HATCH
    M2_DISP_PIN ---> M2_DISP
    M2_HATCH_PIN ---> M2_HATCH
    M3_DISP_PIN ---> M3_DISP
    M3_HATCH_PIN ---> M3_HATCH
```

---

## 2. Master System Pin Connection Table

| From Component | Pin Name / No. | To Component | Target Pin | Wire Color Code | Signal Type | Description |
|:---|:---:|:---|:---:|:---:|:---:|:---|
| **Power Supply** | 5V Output | ESP32-S3 | `5V / VBUS` | 🔴 Red | 5V DC Power | Logic power for ESP32-S3 |
| **Power Supply** | 5V Output | ESP32-C3 | `5V / VBUS` | 🔴 Red | 5V DC Power | Logic power for ESP32-C3 |
| **Power Supply** | 5V Output | Servo Rail | `+5V Rail` | 🔴 Red (Thick 22AWG) | 5V DC Power | Heavy-current servo power rail |
| **Power Supply** | Ground | All Modules | `GND` | ⬛ Black (Thick 22AWG)| Common Ground | **Shared common ground reference** |
| **ESP32-S3** | `GPIO 17` | ESP32-C3 | `GPIO 20` | 🟡 Yellow / Blue | UART TX → RX | S3 Transmits move commands to C3 |
| **ESP32-S3** | `GPIO 18` | ESP32-C3 | `GPIO 21` | 🟢 Green / White | UART RX ← TX | S3 Receives execution response from C3 |
| **ESP32-S3** | `GPIO 5` | IR Sensor | `OUT / DO` | 🟣 Purple | Digital Input | Proximity sensor presence signal |
| **ESP32-S3** | `3V3` | IR Sensor | `VCC` | 🔴 Red | 3.3V DC Power | Sensor power (or 5V if 5V sensor) |
| **ESP32-S3** | `GPIO 6` | Buzzer | `+` (Positive) | 🟠 Orange | PWM Output | LEDC tone drive signal (~2700Hz) |
| **ESP32-C3** | `GPIO 0` | M1 Dispenser Servo | Signal (Pin 3) | 🟡 Yellow / Orange | PWM Signal | Module 1 metering rotor control |
| **ESP32-C3** | `GPIO 1` | M1 Hatch Servo | Signal (Pin 3) | 🟡 Yellow / Orange | PWM Signal | Module 1 retrieval door control |
| **ESP32-C3** | `GPIO 3` | M2 Dispenser Servo | Signal (Pin 3) | 🟡 Yellow / Orange | PWM Signal | Module 2 metering rotor control |
| **ESP32-C3** | `GPIO 4` | M2 Hatch Servo | Signal (Pin 3) | 🟡 Yellow / Orange | PWM Signal | Module 2 retrieval door control |
| **ESP32-C3** | `GPIO 5` | M3 Dispenser Servo | Signal (Pin 3) | 🟡 Yellow / Orange | PWM Signal | Module 3 metering rotor control |
| **ESP32-C3** | `GPIO 6` | M3 Hatch Servo | Signal (Pin 3) | 🟡 Yellow / Orange | PWM Signal | Module 3 retrieval door control |

---

## 3. Microcontroller Pinout Guides & Strapping Rules

### 3.1 ESP32-S3 SuperMini (System Brain)

```
        ESP32-S3 SuperMini Header Layout
               ┌───────────────┐
      USB-C ── │ [ ]     [ ]   │ ── 5V / VBUS  ◄── 5V Power In
        3V3 ── │ [ ]     [ ]   │ ── GND        ◄── Common Ground
    GPIO 17 ── │ [ ]     [ ]   │ ── GPIO 18    (UART1 TX → C3 RX / RX ← C3 TX)
     GPIO 5 ── │ [ ]     [ ]   │ ── GPIO 6     (GPIO 5: IR Sensor / GPIO 6: Buzzer)
               │    ESP32-S3   │
               └───────────────┘
```

#### Detailed Pin Mapping:
- **`5V / VBUS`**: Connects to the main +5V Power Rail.
- **`3V3`**: Connects to IR Proximity Sensor `VCC` (3.3V logic compliant).
- **`GND`**: Connects to Common Ground Bus.
- **`GPIO 17` (TX1)**: UART Transmit line to ESP32-C3 `GPIO 20` (RX0).
- **`GPIO 18` (RX1)**: UART Receive line from ESP32-C3 `GPIO 21` (TX0).
- **`GPIO 5`**: Digital input pin connected to IR Proximity Sensor `OUT`.
- **`GPIO 6`**: PWM pin connected to Piezo Buzzer positive terminal.

> [!CAUTION]
> **ESP32-S3 Reserved / Strapping Pins to AVOID:**
> - `GPIO 0`: Boot mode pin (Must remain HIGH during boot. Do not attach pull-down resistors).
> - `GPIO 45`: VDD_SPI Flash voltage selector.
> - `GPIO 46`: Boot log / ROM code selector.

---

### 3.2 ESP32-C3 SuperMini (Dedicated Servo Controller)

```
        ESP32-C3 SuperMini Header Layout
               ┌───────────────┐
      USB-C ── │ [ ]     [ ]   │ ── 5V / VBUS  ◄── 5V Power In
        GND ── │ [ ]     [ ]   │ ── 3V3
    GPIO 20 ── │ [ ]     [ ]   │ ── GPIO 21    (UART0 RX ← S3 TX / TX → S3 RX)
     GPIO 0 ── │ [ ]     [ ]   │ ── GPIO 1     (M1 Dispenser / M1 Hatch)
     GPIO 3 ── │ [ ]     [ ]   │ ── GPIO 4     (M2 Dispenser / M2 Hatch)
     GPIO 5 ── │ [ ]     [ ]   │ ── GPIO 6     (M3 Dispenser / M3 Hatch)
               │    ESP32-C3   │
               └───────────────┘
```

#### Detailed Pin Mapping:
- **`5V / VBUS`**: Connects to the main +5V Power Rail.
- **`GND`**: Connects to Common Ground Bus.
- **`GPIO 20` (RX0)**: UART Receive line from ESP32-S3 `GPIO 17` (TX1).
- **`GPIO 21` (TX0)**: UART Transmit line to ESP32-S3 `GPIO 18` (RX1).
- **`GPIO 0`**: PWM signal output for Module 1 Dispenser Servo.
- **`GPIO 1`**: PWM signal output for Module 1 Hatch Servo.
- **`GPIO 3`**: PWM signal output for Module 2 Dispenser Servo.
- **`GPIO 4`**: PWM signal output for Module 2 Hatch Servo.
- **`GPIO 5`**: PWM signal output for Module 3 Dispenser Servo.
- **`GPIO 6`**: PWM signal output for Module 3 Hatch Servo.

> [!WARNING]
> **ESP32-C3 Reserved / Strapping Pins to AVOID:**
> - `GPIO 2`: Strapping pin (Boot mode selector). Connecting a servo signal to GPIO 2 will cause startup voltage floating, putting the ESP32-C3 into a boot loop!
> - `GPIO 8`: Direct boot mode check pin.
> - `GPIO 9`: Onboard Boot button pin (Has internal pull-up).

---

## 4. Servo Actuator & Peripheral Wiring Breakout

### 4.1 Standard Servo Cable Wire Color Code
Standard 3-pin RC servo wires (SG90 / MG90S / TowerPro / FEETECH) follow this wire standard:

| Wire Position | Color (Standard 1) | Color (Standard 2) | Signal Name | Connection Destination |
|:---:|:---:|:---:|:---:|:---|
| **Pin 1** | 🟤 Brown | ⬛ Black | **GND** | Common System Ground Bus |
| **Pin 2** | 🔴 Red | 🔴 Red | **VCC (+5V)** | Dedicated 5V Servo Rail |
| **Pin 3** | 🟠 Orange | 🟡 Yellow | **PWM Signal** | Corresponding ESP32-C3 GPIO Pin |

---

### 4.2 Module-by-Module Servo Connection Guide

#### Module 1: Main Base Unit (Pill Container #1)
- **Dispenser Servo (Metering Rotor):**
  - Brown/Black Wire → Common GND Bus
  - Red Wire → 5V Servo Rail
  - Orange/Yellow Wire → **ESP32-C3 `GPIO 0`**
- **Hatch Servo (Access Compartment Door):**
  - Brown/Black Wire → Common GND Bus
  - Red Wire → 5V Servo Rail
  - Orange/Yellow Wire → **ESP32-C3 `GPIO 1`**

#### Module 2: Expansion Unit #1 (Pill Container #2)
- **Dispenser Servo (Metering Rotor):**
  - Brown/Black Wire → Common GND Bus
  - Red Wire → 5V Servo Rail
  - Orange/Yellow Wire → **ESP32-C3 `GPIO 3`**
- **Hatch Servo (Access Compartment Door):**
  - Brown/Black Wire → Common GND Bus
  - Red Wire → 5V Servo Rail
  - Orange/Yellow Wire → **ESP32-C3 `GPIO 4`**

#### Module 3: Expansion Unit #2 (Pill Container #3)
- **Dispenser Servo (Metering Rotor):**
  - Brown/Black Wire → Common GND Bus
  - Red Wire → 5V Servo Rail
  - Orange/Yellow Wire → **ESP32-C3 `GPIO 5`**
- **Hatch Servo (Access Compartment Door):**
  - Brown/Black Wire → Common GND Bus
  - Red Wire → 5V Servo Rail
  - Orange/Yellow Wire → **ESP32-C3 `GPIO 6`**

---

### 4.3 Sensors & Audio Indicators

#### IR Proximity / Presence Sensor (FC-51 / TCRT5000 / VL53L0X)
- **`VCC` Pin**: ESP32-S3 `3V3` Pin (or 5V if required by 5V module version)
- **`GND` Pin**: Common Ground Bus
- **`OUT / DO` Pin**: **ESP32-S3 `GPIO 5`**

#### Piezoelectric Buzzer Module
- **`+` (Positive / Signal) Pin**: **ESP32-S3 `GPIO 6`**
- **`-` (Negative / Ground) Pin**: Common Ground Bus

---

## 5. Modular Expansion Module Connector Pinout

Each physical expansion module (Modules 2 and 3) connects to the main unit using a standardized **4-Pin Connector** (JST-XH 2.54mm or Header Cable):

```
         Expansion Bus Port Pinout (Female Header on Main Box)
         ┌─────────────────────────────────────────────────────┐
         │  [Pin 1]  +5V_SERVO  ──► 5V 3A Servo Rail (Red Wire)│
         │  [Pin 2]  GND        ──► Common Ground (Black Wire) │
         │  [Pin 3]  DISP_PWM   ──► C3 GPIO 3 or 5 (Yellow)    │
         │  [Pin 4]  HATCH_PWM  ──► C3 GPIO 4 or 6 (White)     │
         └─────────────────────────────────────────────────────┘
```

---

## 6. Power Topology & Noise Isolation Guidelines

```
                             5V 3A Power Input
                                     │
                    ┌────────────────┴────────────────┐
                    ▼                                 ▼
            ┌───────────────┐                 ┌───────────────┐
            │ 5V LOGIC RAIL │                 │ 5V SERVO RAIL │
            └───────┬───────┘                 └───────┬───────┘
                    │                                 │
            ┌───────┴───────┐                 ┌───────┴───────┐
            │ ESP32-S3 / C3 │                 │ 470µF 16V Cap │
            └───────┬───────┘                 └───────┬───────┘
                    │                                 │
                    └────────────────┬────────────────┘
                                     ▼
                            Common Ground Bus
```

> [!IMPORTANT]
> ### Electrical Safety Rules:
> 1. **Common Ground:** The ground wire of the USB power input, ESP32-S3, ESP32-C3, sensor, buzzer, and all servos **must connect to a single shared Ground Bus**. Without a common ground, UART serial data and PWM signals will suffer from signal corruption.
> 2. **Decoupling Bulk Capacitor:** Solder a **470 µF / 16V Electrolytic Capacitor** across the 5V Servo Rail and GND right near the servo headers. Servos draw high stall current spikes (up to 500mA each). The capacitor prevents voltage drops that would cause the microcontrollers to reset.
> 3. **Wire Gauge:** Use minimum **22 AWG wire** for the 5V Power Rail and GND Bus. Signal wires (UART, PWM, Proximity) can use **26–28 AWG wire**.

---

## 7. Pre-Power Wiring Verification Checklist

Before plugging in the USB-C power cable, perform the following multimeter continuity and visual checks:

- [ ] **Common Ground Continuity:** Check resistance between S3 GND, C3 GND, Servo GND, and Sensor GND. Must read `< 0.5 Ω`.
- [ ] **No 5V-to-GND Short:** Measure resistance between 5V Power Rail and GND Rail. Must **NOT** be shorted (`0 Ω`).
- [ ] **UART Line Crossover:** Verify that **S3 GPIO 17 (TX)** goes to **C3 GPIO 20 (RX)**, and **S3 GPIO 18 (RX)** goes to **C3 GPIO 21 (TX)**. (TX must connect to RX!).
- [ ] **Servo Supply Separation:** Verify servo red VCC wires are connected to the 5V Servo Rail and **NOT** to the ESP32 3.3V pins.
- [ ] **Strapping Pin Isolation:** Verify that ESP32-C3 `GPIO 2` and ESP32-S3 `GPIO 0` are completely free of unexpected external pull-downs.

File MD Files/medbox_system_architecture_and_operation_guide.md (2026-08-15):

# MedBox — Complete Device Architecture & Operation Guide

This guide provides a comprehensive technical overview of the **MedBox Modular Smart Medication Dispenser**, detailing how the physical device, dual microcontrollers, mechanical dispensing system, cloud backend, and phone push notification system work together.

---

## 1. System Overview & Core Principles

The **MedBox** is an IoT-enabled, modular medication reminder and automated dispensing system. It allows users or caregivers to configure medication schedules via a Web Dashboard hosted on Netlify, while an on-board dual-controller unit handles timekeeping, proximity verification, physical dispensing, and cloud logging.

### Core Design Rules
1. **Modular Principle:** *"One medication type = One medication module."*
   - **Main Module:** Contains system electronics, Wi-Fi, timekeeper, presence sensor, buzzer, and **Module #1 dispensing hardware**.
   - **Expansion Modules:** Purely mechanical expansion units containing Module #2 and Module #3 dispensing hardware (driven by the central controller).
2. **Safety-First Dispensing:** The hatch **never opens** and pills are **never dropped** unless the proximity sensor detects a user in front of the box.
3. **Offline Resilience:** Schedules are synced from Netlify to the ESP32-S3's non-volatile Flash memory (NVS). Once synced, the MedBox dispenses accurately even if Wi-Fi or internet connection drops.

---

## 2. High-Level System Architecture

```mermaid
flowchart TB
    subgraph Cloud["🌐 Cloud Layer (Netlify + ntfy)"]
        UI["Web Dashboard<br/>(HTML/JS Frontend)"]
        API["Netlify Serverless Functions<br/>(/api/sync, /api/notify, /api/dispense-log)"]
        DB[("Netlify Blob Storage<br/>(Schedules & History)")]
        NTFY["ntfy.sh Server"]
        UI <--> API
        API <--> DB
        API --> NTFY
    end

    subgraph Phone["📱 User Mobile Phone"]
        APP["ntfy App / Phone Alerts"]
        NTFY -->|"Push Notification"| APP
    end

    subgraph Hardware["📦 MedBox Physical Device (Main + Expansions)"]
        subgraph S3_Brain["ESP32-S3 SuperMini (Main IoT Brain)"]
            WIFI["Wi-Fi / HTTPS Client"]
            NTP["NTP Time Sync"]
            NVS["NVS Local Schedule Storage"]
            SM["Medication State Machine"]
            PROX["Proximity / IR Sensor"]
            BUZZ["Piezo Buzzer"]
        end

        subgraph C3_Motion["ESP32-C3 SuperMini (Servo Controller)"]
            UART_RX["UART Command Parser"]
            PWM["Servo PWM Driver"]
        end

        subgraph Actuators["Mechanical Modules (Servos & Motors)"]
            M1_DISP["Module 1 Dispenser Servo"]
            M1_HATCH["Module 1 Hatch Servo"]
            M2_DISP["Module 2 Dispenser Servo"]
            M2_HATCH["Module 2 Hatch Servo"]
            M3_DISP["Module 3 Dispenser Servo"]
            M3_HATCH["Module 3 Hatch Servo"]
        end

        S3_Brain <-->|"Hardware UART (115200 Baud)"| C3_Motion
        C3_Motion --> PWM
        PWM --> M1_DISP & M1_HATCH & M2_DISP & M2_HATCH & M3_DISP & M3_HATCH
        PROX --> SM
        BUZZ <-- SM
    end

    API <-->|"HTTPS GET /api/sync<br/>POST /api/dispense-log<br/>POST /api/notify"| WIFI
```

---

## 3. Microcontroller Responsibilities & Hardware Interconnects

The MedBox separates high-level IoT logic from low-level motor actuation across two microcontrollers:

```mermaid
graph LR
    subgraph S3["ESP32-S3 SuperMini (Brain)"]
        direction TB
        S1["Wi-Fi & Cloud Sync"]
        S2["NTP Time Management"]
        S33["State Machine Logic"]
        S4["User Proximity Detection"]
        S5["Buzzer Tone Signals"]
    end

    subgraph C3["ESP32-C3 SuperMini (Motion)"]
        direction TB
        C1["UART Command Receiver"]
        C2["Dispenser Servo PWM"]
        C33["Hatch Servo PWM"]
    end

    S3 -->|"GPIO 17 (TX) ──→ GPIO 2 (RX)"| C3
    C3 -->|"GPIO 3 (TX) ──→ GPIO 18 (RX)"| S3
```

### 3.1 ESP32-S3 SuperMini (System Brain)
- **Wi-Fi Provisioning:** Runs a SoftAP captive portal (`MedBox_WiFi`) on first boot for home Wi-Fi setup.
- **Schedule Sync:** Periodically fetches active schedules from `https://YOUR-SITE.netlify.app/api/sync` every 5 minutes.
- **Time Sync:** Connects to `pool.ntp.org` to maintain localized real-time clock (UTC+8).
- **Proximity Gatekeeper:** Continuously polls the IR/proximity sensor (`GPIO 5`) during alarm windows.
- **Audio Feedback:** Drives the piezo buzzer (`GPIO 6`) for reminder beeps.
- **UART Master:** Transmits binary packets (`CMD_OPEN`, `CMD_DISPENSE`, `CMD_CLOSE`) to the ESP32-C3.

### 3.2 ESP32-C3 SuperMini (Dedicated Servo Controller)
- Accepts single-byte UART commands from the ESP32-S3.
- Precise pulse-width modulation (PWM) control for up to **6 servos** (3 dispenser servos + 3 hatch servos).
- Prevents motor electrical noise and PWM timing jitter from interfering with S3 Wi-Fi stack.

---

## 4. Electrical & Power Topology

```mermaid
block-beta
    columns 3
    block:USB["🔌 USB-C Power Input (5V / 2A-3A)"]:3
    end
    space Protection["Protection Circuit<br/>(Fuse / Reverse Diode)"] space
    block:LogicBus["⚡ 5V Main Power Rail"]:3
    end
    block:LDO["3.3V LDO Regulator"]:1
    block:ServoBus["Servo Power Bus (5V)"]:2
    end
    block:MCU1["ESP32-S3"]:1
    block:MCU2["ESP32-C3"]:1
    block:Servos["Servos (Module 1-3)"]:1
    end

    USB --> Protection
    Protection --> LogicBus
    LogicBus --> LDO
    LogicBus --> ServoBus
    LDO --> MCU1
    LDO --> MCU2
    ServoBus --> Servos
```

> [!IMPORTANT]
> **Common Ground:** All GND pins (ESP32-S3, ESP32-C3, Servos, Power Supply) must share a common reference ground. Servo power is tapped directly from the 5V bus, **never through microcontrollers' internal 3.3V/5V pin outputs**.

---

## 5. Firmware State Machine & Medication Flow

When a scheduled intake time arrives, the ESP32-S3 executes the following finite state machine:

```mermaid
stateDiagram-v2
    [*] --> IDLE
    
    IDLE --> REMINDER : Schedule match (Hour:Minute:Day)
    
    state REMINDER {
        [*] --> BuzzAndNotify
        BuzzAndNotify --> StartRetries
    }
    
    REMINDER --> WAITING_FOR_USER : Initial Buzz + Send ntfy push
    
    state WAITING_FOR_USER {
        [*] --> CheckProximity
        CheckProximity --> ReRemind : Every 5 min (Proximity = False)
        ReRemind --> CheckProximity
    }
    
    WAITING_FOR_USER --> HATCH_OPENING : User Detected (Proximity = True)
    WAITING_FOR_USER --> MISSED_DOSE : Max Retries Exceeded (1 Hour)
    
    MISSED_DOSE --> IDLE : Log "missed" to Netlify + Send Push
    
    HATCH_OPENING --> DISPENSING : UART CMD_OPEN sent to C3
    DISPENSING --> USER_TAKING_MEDICINE : UART CMD_DISPENSE sent to C3
    
    state USER_TAKING_MEDICINE {
        [*] --> WaitHatchTimeout
        WaitHatchTimeout --> CloseHatch : 15 Seconds Elapsed
    }
    
    USER_TAKING_MEDICINE --> HATCH_CLOSING : Timeout reached
    HATCH_CLOSING --> COMPLETED : UART CMD_CLOSE sent to C3
    COMPLETED --> IDLE : Log "dispensed" to Netlify
```

---

## 6. End-to-End Operation Sequence Diagram

The diagram below maps the complete journey from user schedule configuration on the website to pill retrieval and cloud log confirmation:

```mermaid
sequenceDiagram
    autonumber
    actor User as Patient / Caregiver
    participant Web as Web Dashboard
    participant Net as Netlify Backend
    participant ESP as ESP32-S3 (Main)
    participant C3 as ESP32-C3 (Motion)
    participant Phone as Patient Phone (ntfy)

    Note over User, Net: 1. Schedule Setup Phase
    User->>Web: Input Medication (Name, Dose, Time, Days)
    Web->>Net: POST /api/medications
    Net-->>Web: Saved in Netlify Blobs DB

    Note over ESP, Net: 2. Background Sync Phase
    loop Every 5 Minutes
        ESP->>Net: GET /api/sync?deviceId=medbox-001
        Net-->>ESP: Returns active JSON schedules
        ESP->>ESP: Stores in Flash NVS Memory
    end

    Note over ESP: 3. Scheduled Time Reached!
    ESP->>ESP: Trigger State Machine (STATE_REMINDER)
    ESP->>ESP: Sound Piezo Buzzer
    ESP->>Net: POST /api/notify (Medication Reminder)
    Net->>Phone: Push Alert via ntfy.sh ("💊 Medication Reminder")

    Note over ESP, User: 4. User Presence Verification
    ESP->>ESP: Poll Proximity Sensor (STATE_WAITING_FOR_USER)
    User->>ESP: Patient walks up to MedBox
    ESP->>ESP: Proximity Sensor = DETECTED!

    Note over ESP, C3: 5. Dispensing Phase
    ESP->>C3: UART Command: CMD_OPEN (Module ID)
    C3->>C3: Rotate Hatch Servo to OPEN position (90°)
    ESP->>C3: UART Command: CMD_DISPENSE (Module ID)
    C3->>C3: Step Dispenser Rotor (Pill Drops into Pickup Bin)
    
    Note over User: 6. Retrieval & Closure
    User->>ESP: Takes medicine from open compartment
    ESP->>ESP: Wait 15 seconds (STATE_USER_TAKING_MEDICINE)
    ESP->>C3: UART Command: CMD_CLOSE (Module ID)
    C3->>C3: Rotate Hatch Servo to CLOSED position (0°)

    Note over ESP, Net: 7. Logging & Completion
    ESP->>Net: POST /api/dispense-log (Status: "dispensed")
    Net-->>ESP: 200 OK
    ESP->>ESP: Return to STATE_IDLE
```

---

## 7. Mechanical Dispensing Mechanism

Each medication module relies on a gravity-fed cylindrical container paired with an anti-double-feed rotary metering rotor:

```mermaid
graph TD
    A["Top Cylinder Reservoir<br/>(Stores pills vertically)"] -->|"Gravity Feed"| B["Flow Funnel / Hopper Guide"]
    B --> C["Rotary Metering Rotor<br/>(Indexed by Dispenser Servo)"]
    C -->|"1 Index Step (e.g., 15°)"| D["Controlled Drop Chute"]
    D --> E["Pickup Compartment<br/>(Covered by Hatch Servo)"]
```

### Key Mechanical Principles
1. **Gravity Reservoir:** Eliminates complex augers/screws across the main storage volume.
2. **Rotary Pocket Geometry:** The rotor pockets are sized to accommodate one tablet/capsule per position.
3. **Mechanical Anti-Double-Feed:** The rotor wall physically blocks subsequent pills from falling until the next indexing step.
4. **Dual Servo Action per Module:**
   - **Dispenser Servo:** Rotates rotor indexed steps to meter doses.
   - **Hatch Servo:** Opens access door only during active retrieval window.

---

## 8. Summary Checklist for Setup & Verification

| Component | Task | Status Check |
|---|---|---|
| **Netlify Backend** | Linked repo, imported `.env` (`NTFY_TOPIC=med-box-notification`) | Visit `/api/sync?deviceId=medbox-001` → JSON output |
| **ntfy App** | Installed on phone, subscribed to `med-box-notification` | Press **🔔 Send Test Alert** on Website Settings page |
| **ESP32-S3 Firmware** | Flashed `medbox_s3.ino` + LittleFS data files | Serial Monitor shows `API sync: fetched N schedules` |
| **ESP32-C3 Firmware** | Flashed `medbox_c3.ino` | Serial Monitor shows `UART Command Received` |
| **Hardware Wiring** | Shared GND, S3 TX:17 → C3 RX:2, S3 RX:18 ← C3 TX:3 | Motors move on test command |

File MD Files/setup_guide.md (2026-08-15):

# MedBox — ESP32 + Netlify Setup Guide

This guide walks you through everything needed to get your ESP32-S3 talking to your Netlify-hosted web dashboard. Your codebase already has all the integration code written — this guide covers the **deployment and configuration** steps to make it all work together.

---

## Architecture Recap

```mermaid
graph LR
    A["Web Dashboard<br/>(Netlify)"] -->|HTTPS| B["Netlify Functions<br/>(Backend API)"]
    B -->|"@netlify/blobs"| C["Netlify Blob Storage<br/>(Database)"]
    D["ESP32-S3<br/>(MedBox)"] -->|HTTPS GET /api/sync| B
    D -->|HTTPS POST /api/dispense-log| B
    D -->|HTTPS POST /api/notify| B
    D -->|HTTPS POST /api/devices| B
    B -->|ntfy push| E["Phone Notification"]
```

Your ESP32-S3 acts as an HTTPS **client** — it periodically calls your Netlify Functions to sync schedules, log events, and send heartbeats. There is **no inbound connection** to the ESP32.

---

## Part 1: Netlify Setup

### 1.1 Prerequisites

- A [Netlify](https://www.netlify.com/) account (free tier works)
- A [GitHub](https://github.com/) account
- [Node.js](https://nodejs.org/) v18+ installed locally
- [Netlify CLI](https://docs.netlify.com/cli/get-started/) installed:
  ```bash
  npm install -g netlify-cli
  ```

### 1.2 Push Your Repo to GitHub

If your repo isn't already on GitHub:

```bash
cd D:\JCTalosig\Projects\MedDispenser
git remote add origin https://github.com/YOUR_USERNAME/MedDispenser.git
git push -u origin main
```

### 1.3 Create the Netlify Site

**Option A: Via Netlify Dashboard (Recommended)**

1. Go to [app.netlify.com](https://app.netlify.com)
2. Click **"Add new site"** → **"Import an existing project"**
3. Connect to GitHub and select your **MedDispenser** repo
4. Configure the build settings:

   | Setting | Value |
   |---------|-------|
   | **Base directory** | `MedDispenser/web` |
   | **Publish directory** | `MedDispenser/web/frontend` |
   | **Functions directory** | `MedDispenser/web/netlify/functions` |

5. Click **"Deploy site"**

> [!IMPORTANT]
> The **Base directory** must be set to `MedDispenser/web` because your [netlify.toml](file:///d:/JCTalosig/Projects/MedDispenser/MedDispenser/web/netlify.toml) paths are relative to the `web/` folder. Without this, Netlify won't find your functions or frontend.

**Option B: Via CLI**

```bash
cd D:\JCTalosig\Projects\MedDispenser\MedDispenser\web

# Install dependencies first
npm install

# Login to Netlify
netlify login

# Link to a new site
netlify init
```

When prompted:
- Choose **"Create & configure a new site"**
- Set team and site name (e.g., `modular-med-dispenser`)
- Build command: *(leave blank — no build step needed for static HTML)*
- Publish directory: `frontend`

### 1.4 Set Your Custom Site Name

Your firmware's [config.h](file:///d:/JCTalosig/Projects/MedDispenser/MedDispenser/firmware/medbox_s3/config.h#L45) is pre-configured to:

```cpp
#define API_BASE_URL  "https://modular-med-dispenser.netlify.app"
```

To match this:
1. Go to **Site settings** → **Domain management** → **Production domains**
2. Click **"Options"** → **"Edit site name"**
3. Set it to: `modular-med-dispenser`

Or, update `API_BASE_URL` in [config.h](file:///d:/JCTalosig/Projects/MedDispenser/MedDispenser/firmware/medbox_s3/config.h#L45) to match whatever Netlify assigns you.

### 1.5 Verify Deployment

After deployment, verify these endpoints work:

| Endpoint | Expected Response |
|---|---|
| `https://YOUR-SITE.netlify.app/` | Dashboard HTML page loads |
| `https://YOUR-SITE.netlify.app/api/sync?deviceId=test` | `{"serverTime":..., "schedules":[]}` |
| `https://YOUR-SITE.netlify.app/api/devices` | `[]` (empty array) |
| `https://YOUR-SITE.netlify.app/api/medications` | `[]` (empty array) |

### 1.6 Test Locally (Optional)

You can test the full stack locally before deploying:

```bash
cd D:\JCTalosig\Projects\MedDispenser\MedDispenser\web
npm install
netlify dev
```

This starts a local server at `http://localhost:8888` with working Netlify Functions and Blob storage emulation.

---

## Part 2: ESP32-S3 Firmware Setup

### 2.1 Prerequisites

- **Arduino IDE 2.x** (or PlatformIO)
- **ESP32-S3 SuperMini** board
- A USB-C cable for flashing

### 2.2 Install Arduino ESP32 Board Package

1. Open **Arduino IDE** → **File** → **Preferences**
2. In **"Additional Boards Manager URLs"**, add:
   ```
   https://raw.githubusercontent.com/espressif/arduino-esp32/gh-pages/package_esp32_index.json
   ```
3. Go to **Tools** → **Board** → **Boards Manager**
4. Search for **"esp32"** and install **"esp32 by Espressif Systems"** (v3.x recommended)
5. Select your board: **Tools** → **Board** → **ESP32S3 Dev Module** (or closest match for SuperMini)

### 2.3 Install Required Libraries

Install these via **Sketch** → **Include Library** → **Manage Libraries**:

| Library | Purpose |
|---|---|
| **ArduinoJson** (v7+) | JSON parsing for API responses |
| **ESPAsyncWebServer** | Captive portal web server |
| **AsyncTCP** | Dependency for ESPAsyncWebServer |

> [!NOTE]
> `HTTPClient`, `WiFiClientSecure`, `WiFi`, `DNSServer`, `LittleFS`, and `Preferences` are **built-in** to the ESP32 Arduino core — no separate install needed.

### 2.4 Board Configuration

In **Tools** menu, set:

| Setting | Value |
|---|---|
| **Board** | ESP32S3 Dev Module |
| **USB CDC On Boot** | Enabled |
| **Flash Size** | 4MB (or whatever your board has) |
| **Partition Scheme** | Default 4MB with spiffs (or with LittleFS) |
| **Upload Speed** | 921600 |

### 2.5 Upload the Captive Portal Files to LittleFS

Your WiFi manager serves a captive portal from LittleFS. You need to upload the portal HTML files from [data/](file:///d:/JCTalosig/Projects/MedDispenser/MedDispenser/firmware/medbox_s3/data) to the ESP32's filesystem.

1. Install the **ESP32 LittleFS Uploader** plugin for Arduino IDE
   - For Arduino IDE 2.x: Use [arduino-littlefs-upload](https://github.com/earlephilhower/arduino-littlefs-upload)
2. Place your captive portal HTML/CSS/JS files in `firmware/medbox_s3/data/`
3. Upload: **Tools** → **ESP32 Sketch Data Upload** (selects LittleFS partition)

### 2.6 Update config.h

Open [config.h](file:///d:/JCTalosig/Projects/MedDispenser/MedDispenser/firmware/medbox_s3/config.h) and verify/update these values:

```cpp
// Must match your Netlify site URL exactly
#define API_BASE_URL      "https://YOUR-SITE.netlify.app"

// Unique ID for this physical MedBox unit
#define API_DEVICE_ID     "medbox-001"

// Your timezone offset (currently set to UTC+8 for Philippines)
#define NTP_GMT_OFFSET_SEC  28800
```

### 2.7 Flash the Firmware

1. Connect ESP32-S3 via USB-C
2. Open [medbox_s3.ino](file:///d:/JCTalosig/Projects/MedDispenser/MedDispenser/firmware/medbox_s3/medbox_s3.ino)
3. Click **Upload** (→ button)
4. Open **Serial Monitor** at 115200 baud to watch boot logs

---

## Part 3: First-Time Connection Flow

Once the firmware is flashed, here's what happens:

```mermaid
sequenceDiagram
    participant User as You (Phone/Laptop)
    participant ESP as ESP32-S3
    participant Net as Netlify Backend

    Note over ESP: Power on — No saved Wi-Fi
    ESP->>ESP: Starts SoftAP "MedBox_WiFi"
    ESP->>ESP: Starts captive portal on 192.168.4.1

    User->>ESP: Connect to "MedBox_WiFi"
    User->>ESP: Phone auto-opens captive portal
    User->>ESP: Select home Wi-Fi + enter password
    ESP->>ESP: Connects to home Wi-Fi (STA mode)
    ESP->>ESP: Saves credentials to NVS

    Note over ESP: Now has internet access

    ESP->>Net: GET /api/sync?deviceId=medbox-001
    Net-->>ESP: {"serverTime":..., "schedules":[]}

    ESP->>Net: POST /api/devices (heartbeat)
    Net-->>ESP: 200 OK — device registered

    loop Every 5 minutes
        ESP->>Net: GET /api/sync (fetch schedules)
    end
    loop Every 2 minutes
        ESP->>Net: POST /api/devices (heartbeat)
    end
```

### Step-by-Step:

1. **Power on** the ESP32-S3
2. It will create a Wi-Fi network called **`MedBox_WiFi`**
3. **Connect** your phone or laptop to `MedBox_WiFi`
4. A captive portal page should auto-open (or navigate to `192.168.4.1`)
5. **Select your home Wi-Fi** from the scan results and enter the password
6. The ESP32 connects to your Wi-Fi, saves the credentials, and shuts down the AP
7. It immediately begins syncing with your Netlify backend

### Verify Connection:

Open Serial Monitor — you should see:

```
[WIFI] Connected to saved network!
API client initialized
API sync: GET https://modular-med-dispenser.netlify.app/api/sync?deviceId=medbox-001
API sync: fetched 0 schedules
Heartbeat sent
```

---

## Part 4: Using the System

### 4.1 Add a Medication via the Web Dashboard

1. Open your Netlify site URL in a browser
2. Navigate to the **Medications** page
3. Add a medication:
   - Name, module number (1–3), dose count, time, schedule days
4. The medication is stored in Netlify Blob Storage

### 4.2 ESP32 Picks Up the Schedule

- The ESP32 polls `/api/sync` every **5 minutes** (configurable via `API_SYNC_INTERVAL_MS`)
- On sync, it downloads all enabled medications and stores them locally in NVS
- Even if Wi-Fi drops, the ESP32 continues operating from its local schedule copy

### 4.3 At Medication Time

1. ESP32 detects it's time → activates buzzer → sends ntfy push notification
2. Waits for proximity sensor to detect the user
3. Sends UART command to ESP32-C3 → opens hatch → dispenses pills
4. Logs the event via `POST /api/dispense-log`

---

## Part 5: Troubleshooting

### ESP32 can't reach Netlify

| Symptom | Fix |
|---|-----|
| `API sync failed, HTTP -1` | Wi-Fi connected but DNS/TLS issue. Check that `setInsecure()` is called (already done in your code). Ensure your router has internet access. |
| `API sync failed, HTTP 404` | Your Netlify base URL or API redirect paths are wrong. Verify the site name matches `API_BASE_URL`. |
| `API sync failed, HTTP 500` | Backend function error. Check Netlify Functions logs at **Netlify Dashboard** → **Functions** → click the function → view logs. |
| `[WIFI] Saved network failed` | Wrong password or SSID changed. The ESP32 will automatically fall back to AP mode so you can re-enter credentials. |

### Netlify Functions Not Working

1. Check **Netlify Dashboard** → **Functions** tab — all 6 functions should appear:
   - `devices`, `dispense-log`, `medications`, `notify`, `schedules`, `sync`
2. If missing, verify the **Base directory** is set to `MedDispenser/web` in site settings
3. Check the **Functions log** for runtime errors

### Reset Wi-Fi on ESP32

If you need to re-provision Wi-Fi, you can:
- Call `wifiForgetNetwork()` in your code (triggered by a button, etc.)
- Or manually erase NVS: **Tools** → **Erase All Flash Before Sketch Upload** → re-upload

---

## Part 6: ESP32-C3 (Servo Controller) Setup

The C3 firmware is in [firmware/medbox_c3/](file:///d:/JCTalosig/Projects/MedDispenser/MedDispenser/firmware/medbox_c3). It's simpler since it only receives UART commands from the S3.

1. Select board: **ESP32C3 Dev Module**
2. Flash [the C3 firmware](file:///d:/JCTalosig/Projects/MedDispenser/MedDispenser/firmware/medbox_c3)
3. Wire UART between S3 and C3:

```
ESP32-S3 GPIO 17 (TX) ──→ ESP32-C3 RX
ESP32-S3 GPIO 18 (RX) ←── ESP32-C3 TX
Common GND ─────────────── GND
```

> [!WARNING]
> Pin assignments in [config.h](file:///d:/JCTalosig/Projects/MedDispenser/MedDispenser/firmware/medbox_s3/config.h#L18-L19) are marked as **NOT FINALIZED**. Verify against your actual board's available GPIOs before wiring.

---

## Quick Reference: API Endpoints

| Endpoint | Method | Who Calls | Purpose |
|---|---|---|---|
| `/api/sync` | GET | ESP32 | Fetch medication schedules |
| `/api/dispense-log` | POST | ESP32 | Log a dispense event |
| `/api/notify` | POST | ESP32 | Trigger ntfy push notification |
| `/api/devices` | GET/POST | ESP32 + Web | Device registration & heartbeat |
| `/api/medications` | GET/POST | Web UI | CRUD medications |
| `/api/schedules` | GET | Web UI | View schedule calendar |

---

## Summary Checklist

- [ ] Push repo to GitHub
- [ ] Create Netlify site linked to the repo (base dir: `MedDispenser/web`)
- [ ] Set site name to match `API_BASE_URL` in config.h (or update config.h)
- [ ] Verify Netlify endpoints return valid JSON
- [ ] Install Arduino ESP32 board package + required libraries
- [ ] Update `API_BASE_URL` in config.h if needed
- [ ] Flash LittleFS data (captive portal files)
- [ ] Flash medbox_s3.ino to ESP32-S3
- [ ] Connect to `MedBox_WiFi` AP and provision home Wi-Fi
- [ ] Verify sync via Serial Monitor
- [ ] Add medications via web dashboard
- [ ] Confirm ESP32 picks up schedules on next sync

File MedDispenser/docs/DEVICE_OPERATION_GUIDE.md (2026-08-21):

# MedBox — Complete Device Architecture & Operation Guide

> **Last Updated:** 2026-08-22 — Reflects IR-gated hatch opening, dispense-first flow, correct UART pins, modified 360° servo, active buzzer, dual time sync, and all recent firmware fixes.

This guide provides a comprehensive technical overview of the **MedBox Modular Smart Medication Dispenser**, detailing how the physical device, dual microcontrollers, mechanical dispensing system, cloud backend, and phone push notification system work together.

---

## 1. System Overview & Core Principles

The **MedBox** is an IoT-enabled, modular medication reminder and automated dispensing system. It allows users or caregivers to configure medication schedules via a Web Dashboard hosted on Netlify, while an on-board dual-controller unit handles timekeeping, proximity verification, physical dispensing, and cloud logging.

### Core Design Rules
1. **Modular Principle:** *"One medication type = One medication module."*
   - **Main Module:** Contains system electronics, Wi-Fi, timekeeper, presence sensor, buzzer, and **Module #1 dispensing hardware**.
   - **Expansion Modules:** Purely mechanical expansion units containing Module #2 and Module #3 dispensing hardware (driven by the central controller).
2. **IR-Gated Safety:** The hatch **never opens** unless the IR proximity sensor detects a user's hand in front of the box. Pills are dispensed behind a closed hatch first, then the hatch opens only on IR trigger.
3. **Offline Resilience:** Schedules are synced from Netlify to the ESP32-S3's non-volatile Flash memory (NVS). Once synced, the MedBox dispenses accurately even if Wi-Fi or internet connection drops.

---

## 2. High-Level System Architecture

```mermaid
flowchart TB
    subgraph Cloud["🌐 Cloud Layer (Netlify + ntfy)"]
        UI["Web Dashboard<br/>(HTML/JS Frontend)"]
        API["Netlify Serverless Functions<br/>(/api/sync, /api/notify, /api/dispense-log)"]
        DB[("Netlify Blob Storage<br/>(Schedules & History)")]
        NTFY["ntfy.sh Server"]
        UI <--> API
        API <--> DB
        API --> NTFY
    end

    subgraph Phone["📱 User Mobile Phone"]
        APP["ntfy App / Phone Alerts"]
        NTFY -->|"Push Notification"| APP
    end

    subgraph Hardware["📦 MedBox Physical Device (Main + Expansions)"]
        subgraph S3_Brain["ESP32-S3 SuperMini (Main IoT Brain)"]
            WIFI["Wi-Fi / HTTP(S) Client"]
            NTP["NTP + Server Time Sync"]
            NVS["NVS Local Schedule Storage"]
            SM["Medication State Machine"]
            PROX["IR Proximity Sensor (GPIO 5)"]
            BUZZ["Active Buzzer (GPIO 6)"]
        end

        subgraph C3_Motion["ESP32-C3 SuperMini (Servo Controller)"]
            UART_RX["UART Command Parser"]
            PWM["Servo PWM Driver"]
        end

        subgraph Actuators["Mechanical Modules (Servos & Motors)"]
            M1_DISP["Module 1 Dispenser Servo (360°)"]
            M1_HATCH["Module 1 Hatch Servo (0°–90°)"]
            M2_DISP["Module 2 Dispenser Servo (360°)"]
            M2_HATCH["Module 2 Hatch Servo (0°–90°)"]
            M3_DISP["Module 3 Dispenser Servo (360°)"]
            M3_HATCH["Module 3 Hatch Servo (0°–90°)"]
        end

        S3_Brain <-->|"Hardware UART (115200 Baud)<br/>S3 TX:GPIO1 → C3 RX:GPIO20<br/>S3 RX:GPIO2 ← C3 TX:GPIO21"| C3_Motion
        C3_Motion --> PWM
        PWM --> M1_DISP & M1_HATCH & M2_DISP & M2_HATCH & M3_DISP & M3_HATCH
        PROX --> SM
        BUZZ <-- SM
    end

    API <-->|"HTTP(S) GET /api/sync<br/>POST /api/dispense-log<br/>POST /api/notify<br/>GET /api/dispense-command"| WIFI
```

---

## 3. Microcontroller Responsibilities & Hardware Interconnects

The MedBox separates high-level IoT logic from low-level motor actuation across two microcontrollers:

```mermaid
graph LR
    subgraph S3["ESP32-S3 SuperMini (Brain)"]
        direction TB
        S1["Wi-Fi & Cloud Sync"]
        S2["NTP + Server Time Sync"]
        S33["State Machine Logic"]
        S4["IR Proximity Detection (GPIO 5)"]
        S5["Active Buzzer (GPIO 6)"]
    end

    subgraph C3["ESP32-C3 SuperMini (Motion)"]
        direction TB
        C1["UART Command Receiver"]
        C2["Dispenser Servo PWM (360° continuous)"]
        C33["Hatch Servo PWM (0°–90°)"]
    end

    S3 -->|"GPIO 1 (TX) ──→ GPIO 20 (RX)"| C3
    C3 -->|"GPIO 21 (TX) ──→ GPIO 2 (RX)"| S3
```

### 3.1 ESP32-S3 SuperMini (System Brain)
- **Wi-Fi Provisioning:** Runs a SoftAP captive portal (`MedBox_WiFi`) on first boot for home Wi-Fi setup.
- **Schedule Sync:** Periodically fetches active schedules from backend API every 5 minutes.
- **Time Sync (Dual-Path):**
  - **Primary:** NTP via `pool.ntp.org` (UTC+8, retries every 5 seconds until synced)
  - **Fallback:** Server epoch from `/api/sync` response → `timeSetEpoch()` sets system clock instantly
- **IR Proximity Gatekeeper:** Continuously polls the IR proximity sensor (`GPIO 5`) during `STATE_WAITING_FOR_USER`. Hatch opens **ONLY** when hand is detected.
- **Active Buzzer:** Drives active buzzer (`GPIO 6`) via `digitalWrite(HIGH/LOW)` — NOT PWM.
- **UART Master:** Transmits text commands (`DISPENSE,N,count`, `OPEN,N`, `CLOSE,N`) to the ESP32-C3.
- **Command Polling:** Polls `/api/dispense-command` every 10 seconds for hardware test commands from the web Settings panel.

### 3.2 ESP32-C3 SuperMini (Dedicated Servo Controller)
- Uses `HardwareSerial(0)` on GPIO 20/21 (ESP32-C3 has only 1 UART peripheral)
- **USB CDC On Boot = Enabled** in Arduino IDE board settings
- Parses text UART commands and controls up to **6 servos** (3 dispenser + 3 hatch)
- Dispenser servos use `attach()` → `write(180)` → `delay(2400ms)` → `detach()` per revolution
- Hatch servos use standard `attach()` → `write(angle)` → `delay(300ms)` → `detach()`

---

## 4. Electrical & Power Topology

```mermaid
block-beta
    columns 3
    block:USB["🔌 USB-C Power Input (5V / 2A-3A)"]:3
    end
    space Protection["Protection Circuit<br/>(Fuse / Reverse Diode)"] space
    block:LogicBus["⚡ 5V Main Power Rail"]:3
    end
    block:LDO["3.3V LDO Regulator"]:1
    block:ServoBus["Servo Power Bus (5V)"]:2
    end
    block:MCU1["ESP32-S3"]:1
    block:MCU2["ESP32-C3"]:1
    block:Servos["Servos (Module 1-3)"]:1
    end

    USB --> Protection
    Protection --> LogicBus
    LogicBus --> LDO
    LogicBus --> ServoBus
    LDO --> MCU1
    LDO --> MCU2
    ServoBus --> Servos
```

> [!IMPORTANT]
> **Common Ground:** All GND pins (ESP32-S3, ESP32-C3, Servos, Power Supply) must share a common reference ground. Servo power is tapped directly from the 5V bus, **never through microcontrollers' internal 3.3V/5V pin outputs**.

---

## 5. Firmware State Machine & Medication Flow

When a scheduled intake time arrives, the ESP32-S3 executes the following finite state machine:

```mermaid
stateDiagram-v2
    [*] --> IDLE
    
    IDLE --> REMINDER : Schedule match (Hour:Minute:Day)
    
    state REMINDER {
        [*] --> BuzzAndNotify
        BuzzAndNotify --> SendPush
    }
    
    REMINDER --> DISPENSING : Buzzer alarm + ntfy push sent

    state DISPENSING {
        [*] --> SpinServo
        SpinServo --> WaitRevolutions
        note right of SpinServo : Hatch stays CLOSED (0°)
    }

    DISPENSING --> WAITING_FOR_USER : Pill(s) dropped into internal compartment
    
    state WAITING_FOR_USER {
        [*] --> PollIRSensor
        PollIRSensor --> ReRemind : Every 5 min (IR = not detected)
        ReRemind --> PollIRSensor
    }
    
    WAITING_FOR_USER --> HATCH_OPENING : 🔴 IR Sensor Detected (Hand Present)
    WAITING_FOR_USER --> MISSED_DOSE : Max Retries Exceeded (1 Hour)
    
    MISSED_DOSE --> IDLE : Log "missed" to Netlify + Send Push
    
    HATCH_OPENING --> USER_TAKING_MEDICINE : UART CMD_OPEN → Hatch 90°
    
    state USER_TAKING_MEDICINE {
        [*] --> WaitRetrieve
        WaitRetrieve --> CloseHatch : 5 Seconds Elapsed
    }
    
    USER_TAKING_MEDICINE --> HATCH_CLOSING : Timeout reached
    HATCH_CLOSING --> COMPLETED : UART CMD_CLOSE → Hatch 0°
    COMPLETED --> IDLE : Log "dispensed" to Netlify
```

### Key Behavioral Rules

| Rule | Detail |
|---|---|
| **Dispense-First** | Dispenser servo spins behind closed hatch. Pills drop into internal staging compartment. |
| **IR-Gated Hatch** | Hatch opens ONLY when `proximityIsDetected() == true`. Never opens automatically with buzzer/dispenser. |
| **UART Spam Prevention** | `_cmdSentInState` flag ensures each UART command is sent exactly once per state entry. Resets in `_enterState()`. |
| **Multi-Pill Dosing** | `uartSendCommandEx(CMD_DISPENSE, moduleId, pillsPerDose)` sends pill count to C3. C3 executes N consecutive revolutions. |

---

## 6. End-to-End Operation Sequence Diagram

```mermaid
sequenceDiagram
    autonumber
    actor User as Patient / Caregiver
    participant Web as Web Dashboard
    participant Net as Netlify Backend
    participant ESP as ESP32-S3 (Main)
    participant C3 as ESP32-C3 (Motion)
    participant Phone as Patient Phone (ntfy)

    Note over User, Net: 1. Schedule Setup Phase
    User->>Web: Input Medication (Name, Dose, Time, Days)
    Web->>Net: POST /api/medications
    Net-->>Web: Saved in Netlify Blobs DB

    Note over ESP, Net: 2. Background Sync Phase
    loop Every 5 Minutes
        ESP->>Net: GET /api/sync?deviceId=medbox-001
        Net-->>ESP: Returns JSON schedules + serverTime
        ESP->>ESP: Store in NVS Flash + sync system clock
    end

    Note over ESP: 3. Scheduled Time Reached!
    ESP->>ESP: Trigger State Machine (STATE_REMINDER)
    ESP->>ESP: Sound Active Buzzer (3 beeps × 500ms)
    ESP->>Net: POST /api/notify (Medication Reminder)
    Net->>Phone: Push Alert via ntfy.sh ("💊 Medication Reminder")

    Note over ESP, C3: 4. Dispensing Phase (Hatch CLOSED)
    ESP->>C3: UART: DISPENSE,1,2 (Module 1, 2 pills)
    C3->>C3: Spin dispenser servo 360° × 2 revolutions
    C3->>C3: detach() → hard stop motor
    C3-->>ESP: OK,DISPENSE,1
    ESP->>ESP: Pill(s) dropped. STATE_WAITING_FOR_USER

    Note over ESP, User: 5. IR Proximity Verification (Hatch still CLOSED)
    ESP->>ESP: Poll IR Sensor (STATE_WAITING_FOR_USER)
    User->>ESP: Places hand near IR sensor
    ESP->>ESP: 🔴 proximityIsDetected() = true!

    Note over ESP, C3: 6. Hatch Opens (IR-Triggered)
    ESP->>C3: UART: OPEN,1 (Module 1)
    C3->>C3: Rotate Hatch Servo to 90° (OPEN)
    C3-->>ESP: OK,OPEN,1

    Note over User: 7. Retrieval & Closure
    User->>ESP: Takes medicine from open compartment
    ESP->>ESP: Wait 5 seconds (STATE_USER_TAKING_MEDICINE)
    ESP->>C3: UART: CLOSE,1 (Module 1)
    C3->>C3: Rotate Hatch Servo to 0° (CLOSED)
    C3-->>ESP: OK,CLOSE,1

    Note over ESP, Net: 8. Logging & Completion
    ESP->>Net: POST /api/dispense-log (Status: "dispensed")
    Net-->>ESP: 200 OK
    ESP->>ESP: Return to STATE_IDLE
```

---

## 7. Mechanical Dispensing Mechanism

Each medication module relies on a gravity-fed cylindrical container paired with a modified SG90R 360° continuous rotation servo:

```mermaid
graph TD
    A["Top Cylinder Reservoir<br/>(Stores pills vertically)"] -->|"Gravity Feed"| B["Flow Funnel / Hopper Guide"]
    B --> C["Rotary Metering Rotor<br/>(SG90R Modified 360° Servo)"]
    C -->|"1 Full 360° Revolution = 1 Pill"| D["Controlled Drop Chute"]
    D --> E["Internal Staging Compartment<br/>(Behind Closed Hatch)"]
    E -->|"IR Sensor Triggered"| F["Hatch Opens 90°<br/>(User Retrieves Pill)"]
```

### Key Mechanical Principles
1. **Gravity Reservoir:** Eliminates complex augers/screws across the main storage volume.
2. **Full 360° Revolution Per Pill:** The modified SG90R servo (potentiometer removed, stopper removed) makes exactly 1 full revolution per pill dose. Multiple pills = multiple revolutions.
3. **Mechanical Anti-Double-Feed:** The rotor wall physically blocks subsequent pills from falling until the next revolution completes.
4. **Dual Servo Action per Module:**
   - **Dispenser Servo (SG90R 360°):** Rotates 360° per pill behind closed hatch. Uses `write(180)` for full speed → `detach()` for hard stop.
   - **Hatch Servo (SG90 Standard):** Opens to 90° ONLY when IR sensor is triggered. Returns to 0° after 5-second retrieval window.

### Servo Control Method (Modified SG90R)

```
Per pill revolution:
  attach(pin)         → Connect PWM signal
  write(180)          → Full speed forward
  delay(2400ms)       → Wait for 1 complete 360° revolution
  detach()            → Cut PWM = instant motor stop

Repeat for each pill in dose (300ms pause between revolutions)
```

> [!WARNING]
> **Why `detach()` instead of `write(90)`?** The SG90R has its internal potentiometer disconnected. Without potentiometer feedback, the servo's internal controller cannot find "center" (90°). Sending `write(90)` results in continuous creep/spin. Only `detach()` fully cuts the PWM pulse stream, forcing the motor driver IC to power off the motor coils.

---

## 8. Web Dashboard & Schedule Checker

The Web Dashboard runs a **client-side schedule checker** that operates independently of the ESP32:

| Feature | Detail |
|---|---|
| **Check Interval** | Every 30 seconds via `setInterval` |
| **Scope** | Runs on **ALL pages** (dashboard, medications, settings, history) |
| **Deduplication** | Uses `Set()` with date-keyed trigger IDs to prevent duplicate triggers |
| **Action** | When schedule time matches → sends browser notification + `POST /api/dispense-command` |
| **ESP32 Pickup** | ESP32-S3 polls `/api/dispense-command` every 10 seconds and executes the command |

### Hardware Test Panel (Settings Page)

The Settings page includes a Hardware Test Panel for manual testing:
- **Ping Test** — Sends `PING,0` to verify S3 ↔ C3 UART communication
- **Buzzer Test** — Triggers active buzzer on ESP32-S3
- **Hatch Open/Close** — Sends `OPEN,N` / `CLOSE,N` for each module
- **Dispense Test** — Sends `DISPENSE,N,count` with selectable pill count (1-3)
- **IR Sensor Test** — Reads proximity sensor state

---

## 9. Summary Checklist for Setup & Verification

| Component | Task | Status Check |
|---|---|---|
| **Netlify Backend** | Linked repo, imported `.env` (`NTFY_TOPIC=med-box-notification`) | Visit `/api/sync?deviceId=medbox-001` → JSON output |
| **ntfy App** | Installed on phone, subscribed to `med-box-notification` | Press **🔔 Send Test Alert** on Website Settings page |
| **ESP32-S3 Firmware** | Flashed `medbox_s3.ino` | Serial Monitor shows `NTP synced` or `System time synced from server` |
| **ESP32-C3 Firmware** | Flashed `medbox_c3.ino` (USB CDC On Boot = Enabled) | Serial Monitor shows `Servo controller initialized: 3 modules attached` |
| **Hardware Wiring** | Shared GND, S3 TX:GPIO1 → C3 RX:GPIO20, S3 RX:GPIO2 ← C3 TX:GPIO21 | Serial shows `PONG sent` on ping test |
| **IR Sensor** | Connected to S3 GPIO 5, active LOW | Place hand near sensor → Serial shows `IR Sensor Activated!` |
| **Active Buzzer** | Connected to S3 GPIO 6, direct digitalWrite | Press buzzer test button → buzzer sounds |
| **Dispenser Servo** | SG90R modified (potentiometer removed, stopper removed) on C3 GPIO 0 | Press dispense test → servo completes 1 full 360° revolution and stops |
| **Hatch Servo** | Standard SG90 on C3 GPIO 1 | Press open test → hatch opens 90°, close test → returns to 0° |

---

## 10. Revision History

| Date | Change |
|---|---|
| 2026-08-22 | Updated state machine: dispense-first flow, IR-gated hatch opening |
| 2026-08-22 | Fixed UART pins: S3 GPIO 1 (TX) / GPIO 2 (RX) ↔ C3 GPIO 20 (RX) / GPIO 21 (TX) |
| 2026-08-22 | Added `uartSendCommandEx()` for multi-pill dose count passthrough (`DISPENSE,N,count`) |
| 2026-08-22 | Fixed modified SG90R 360° servo: `write(180)` + `detach()` hard stop |
| 2026-08-22 | Fixed active buzzer: `digitalWrite(HIGH/LOW)` instead of PWM `ledcWrite` |
| 2026-08-22 | Fixed UART command spam: added `_cmdSentInState` flag, resets in `_enterState()` |
| 2026-08-22 | Fixed ESP32-C3 UART: uses `HardwareSerial(0)` on pins 20/21 (C3 has only 1 UART) |
| 2026-08-22 | Fixed NTP retry: reduced from 60s to 5s; added `timeSetEpoch()` from server sync |
| 2026-08-22 | Fixed web schedule checker: now runs on ALL pages, not just dashboard |
| 2026-08-22 | Added HTTP/HTTPS dual compatibility in `api_client.cpp` |
| 2026-08-22 | Added Hardware Test Panel on Settings page |

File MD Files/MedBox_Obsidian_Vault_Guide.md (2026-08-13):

# MedBox — Obsidian Vault Guide

> How to use the `ObsidianMem/` vault as the project's knowledge base.

---

## Opening the Vault

1. Open Obsidian
2. Click **Open folder as vault**
3. Select `d:\Antigravity\Projects\Med Dispenser\ObsidianMem`
4. The vault loads with the index at `00 - Index.md`

---

## Vault Structure

```
ObsidianMem/
├── 00 - Index.md                  Master index / Map of Content
├── 01 - Architecture/             System design (4 notes)
├── 02 - Firmware/                 Firmware design (5 notes)
├── 03 - Hardware/                 Component selection (4 notes)
├── 04 - Mechanical/               Physical design (4 notes)
├── 05 - Web & IoT/               Software/cloud (5 notes)
├── 06 - Decision Log/            Decisions + open questions (2 notes)
├── 07 - Build Log/               Prototyping journal (add as you go)
└── Templates/                    Reusable note templates (2 templates)
```

Sections are numbered for sort order. Each section focuses on one engineering domain.

---

## How to Use

### Daily Reference
- Open `00 - Index.md` to navigate to any topic
- Use `Ctrl+O` (Quick Open) to jump to any note by name
- Use `[[wikilinks]]` in notes to cross-reference related topics

### Recording Decisions
1. Open `Templates/Decision Template.md`
2. Copy the content
3. Create a new note in `06 - Decision Log/`
4. Paste and fill in the template
5. Add a link from `Finalized Decisions.md` or `Open Questions.md`

### Build Logging
1. Open `Templates/Build Log Entry Template.md`
2. Copy the content
3. Add a new entry in `07 - Build Log/Build Log.md` or create a separate note
4. Fill in measurements, issues, photos

### Updating Notes
- When a decision changes, update the relevant note and `Finalized Decisions.md`
- Mark status as FINALIZED, RECOMMENDED, OPTIONAL, UNDECIDED, or REJECTED
- Add date stamps to significant changes

---

## Navigation Tips

| Action | Shortcut |
|---|---|
| Quick Open | `Ctrl+O` |
| Search | `Ctrl+Shift+F` |
| Back | `Alt+←` |
| Graph View | `Ctrl+G` |
| Toggle sidebar | `Ctrl+B` |

### Graph View
Press `Ctrl+G` to see the full knowledge graph. Notes with more `[[wikilinks]]` appear more connected. This helps visualize which subsystems are most interrelated.

---

## Relationship to Other Project Files

| Location | Purpose |
|---|---|
| `ObsidianMem/` | Living knowledge base (this vault) |
| `MedDispenser/` | Source code (firmware + web) |
| `MedDispenser/docs/` | In-repo quick-reference docs |
| `MD Files/` | Standalone specification & reference documents |

The Obsidian vault is the **thinking and decision layer**. The `MedDispenser/docs/` folder is the **developer quick-reference layer**. The `MD Files/` folder holds **formal reference documents**.

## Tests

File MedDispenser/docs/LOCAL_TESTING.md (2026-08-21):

# MedBox — Local Testing Guide

This guide explains how to run and test the MedBox web dashboard, backend API functions, and ESP32 hardware flow on `localhost` before deploying to Netlify.

---

## 1. Running the Local Development Server

Netlify CLI serves both the static web frontend (`web/frontend/`) and the serverless backend functions (`web/netlify/functions/`) locally, along with an in-memory Netlify Blobs store.

### Steps:
1. Open a terminal in the `web` directory:
   ```powershell
   cd web
   ```
2. Launch the Netlify development server:
   ```powershell
   npx netlify dev
   ```
3. Open your browser and navigate to:
   ```
   http://localhost:8888
   ```

---

## 2. Testing Frontend & Backend Features Locally

### A. Manual Test Alert & Hardware Trigger
1. Navigate to **Medications** (`http://localhost:8888/medications.html`).
2. Click the **"🔔 Test Alert"** button on any medication card.
3. **Expected Behavior:**
   - Sends a push notification via `ntfy` to your mobile device.
   - Queues a pending dispense command in the local `/api/dispense-command` store.
   - Toast popup confirms success in the browser interface.

### B. Automatic Scheduled Notifications
1. Navigate to **Dashboard** (`http://localhost:8888/index.html`).
2. Add a test medication with a scheduled time **1–2 minutes in the future**.
3. Keep the Dashboard page open.
4. **Expected Behavior:**
   - Every 30 seconds, the client-side schedule checker compares local time against active schedules.
   - When the scheduled minute arrives:
     - Prominent warning toast appears on screen.
     - `ntfy` notification is sent to your phone.
     - Dispense command is queued for the ESP32.

---

## 3. Connecting Physical ESP32 Hardware to Localhost (Optional)

To test the physical ESP32-S3 board with your local development server:

1. **Find your Local IP Address:**
   ```powershell
   ipconfig
   ```
   *Look for your IPv4 address (e.g., `192.168.1.5`).*

2. **Update Hardware Configuration:**
   In `firmware/medbox_s3/config.h`, update `API_BASE_URL` to point to your computer's local IP address:
   ```cpp
   // Point to local development server
   #define API_BASE_URL "http://192.168.1.5:8888"
   ```

3. **Ensure Network Connectivity:**
   - Both your computer and the ESP32 must be connected to the **same Wi-Fi network**.
   - Compile and flash the updated firmware to the ESP32-S3.

4. **Verify Hardware Execution:**
   - Open Arduino IDE Serial Monitor (115200 baud).
   - During sync (`/api/sync`), the ESP32 will pick up the queued dispense commands.
   - The state machine will execute:
     1. **Buzzer Alarm** sound pattern
     2. **IR Proximity Sensor** detection loop
     3. **Servo Hatch Opening** command (`OPEN`)
     4. **Servo Dispenser** movement (`DISPENSE`)
     5. **Servo Hatch Closing** command (`CLOSE`)

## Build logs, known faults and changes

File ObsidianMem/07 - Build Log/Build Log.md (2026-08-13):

# Build Log

> Add entries here as you prototype and test. Use the [[../Templates/Build Log Entry Template|Build Log Entry Template]].

## Entries
_No entries yet — start logging when prototyping begins._

---

Example entry format:
```
## 2026-08-15 — First Servo Test
- Tested MG90S with ESP32-C3
- 15° step moves rotor one pocket
- Current draw measured: 280 mA under load
- Issue: slight overshoot at fast speed
- Action: reduce servo speed, add settling delay
```

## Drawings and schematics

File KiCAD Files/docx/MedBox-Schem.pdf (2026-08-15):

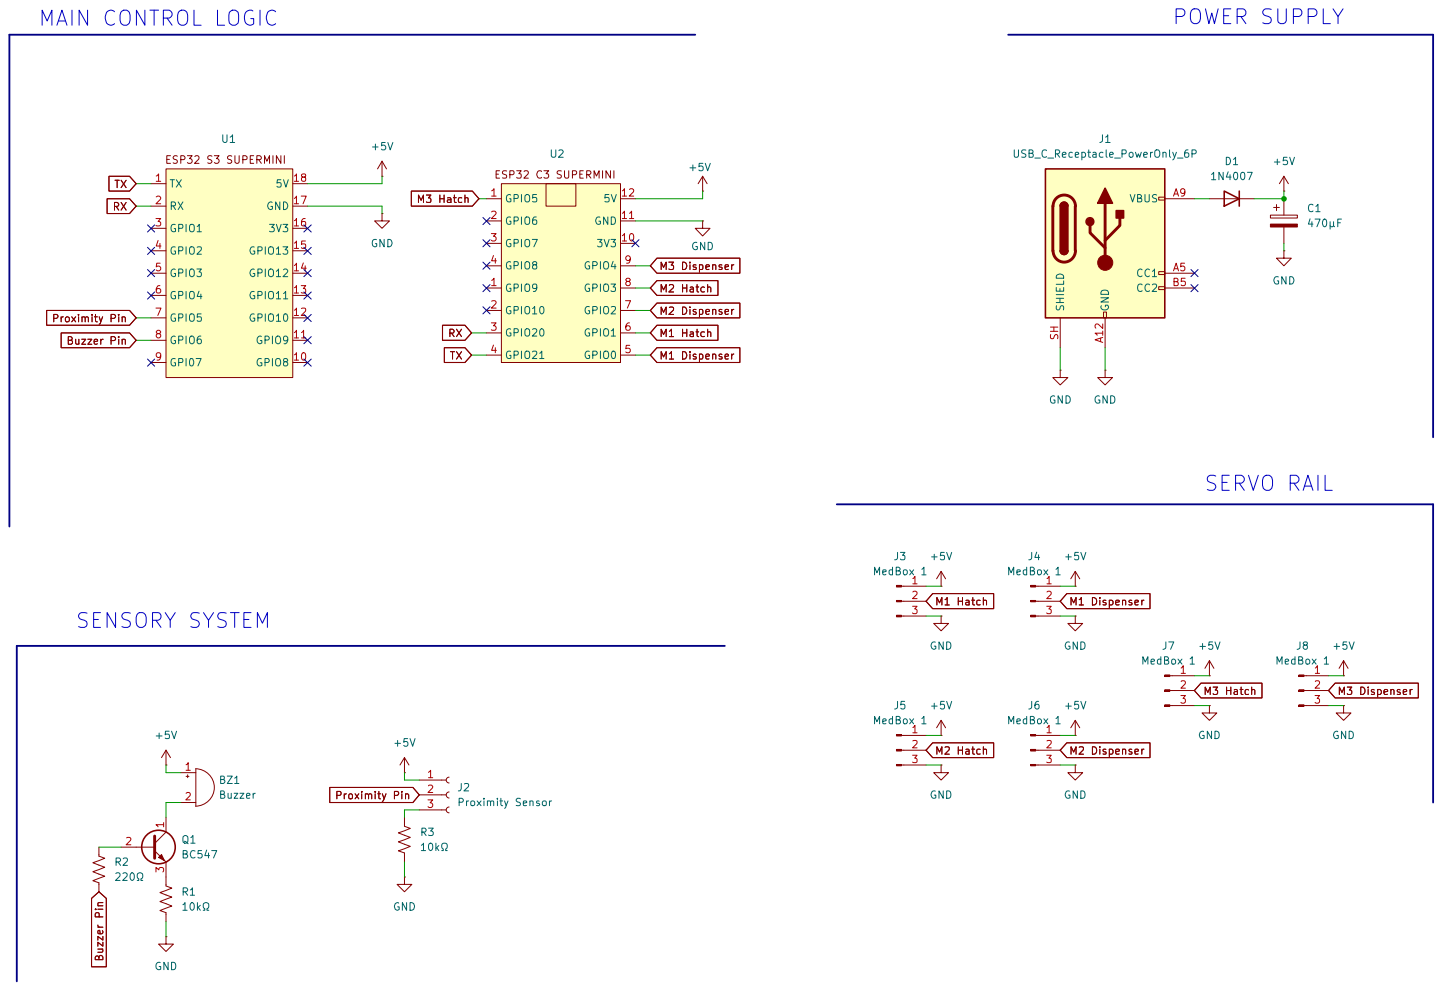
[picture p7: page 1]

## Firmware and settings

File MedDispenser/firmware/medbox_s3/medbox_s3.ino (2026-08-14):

/*
 * MedBox ESP32-S3 — Main Firmware
 * =================================
 * System brain: Wi-Fi, schedules, time, proximity, buzzer, UART to C3.
 *
 * Architecture:
 *   - Non-blocking state machine in loop()
 *   - Modular subsystems (each .h/.cpp pair)
 *   - UART command interface to ESP32-C3 servo controller
 *
 * Arduino IDE Board: ESP32-S3 Dev Module (or SuperMini variant)
 * Partition Scheme: Default 4MB with spiffs (NVS + LittleFS for portal assets)
 */

#include "config.h"
#include "nvs_store.h"
#include "wifi_manager.h"
#include "time_manager.h"
#include "schedule_manager.h"
#include "state_machine.h"
#include "proximity.h"
#include "buzzer.h"
#include "uart_command.h"
#include "api_client.h"

// Copy from firmware/shared/ — keep in sync with canonical version
#include "protocol.h"

// ── Forward declarations ───────────────────────────────────────────────────
void handleSerialDebug();

void setup() {
  // Debug serial
  Serial.begin(SERIAL_BAUD);
  delay(1000);  // Allow USB serial to initialize
  Serial.println(F("=== MedBox S3 Starting ==="));

  // Initialize subsystems
  buzzerInit();
  proximityInit();
  uartCommandInit();
  nvsStoreInit();
  wifiManagerInit();
  timeManagerInit();
  scheduleManagerInit();
  stateMachineInit();
  apiClientInit();

  Serial.println(F("=== MedBox S3 Ready ==="));

  // Short startup beep
  buzzerBeep(200);
}

void loop() {
  // ── Non-blocking subsystem updates ─────────────────────────────────────
  wifiManagerUpdate();        // WiFi provisioning + connection management
  timeManagerUpdate();        // NTP sync checks
  scheduleManagerUpdate();    // Evaluate active schedules
  stateMachineUpdate();       // Run medication event state machine
  proximityUpdate();          // Read proximity sensor
  buzzerUpdate();             // Handle non-blocking buzzer patterns
  uartCommandUpdate();        // Process any pending UART responses
  apiClientUpdate();          // Periodic backend sync

  // ── Debug interface ────────────────────────────────────────────────────
  handleSerialDebug();
}

// ── Serial debug commands ────────────────────────────────────────────────
// Type commands into the Arduino Serial Monitor for testing.
void handleSerialDebug() {
  if (!Serial.available()) return;

  String cmd = Serial.readStringUntil('\n');
  cmd.trim();

  if (cmd == "status") {
    Serial.println(F("--- MedBox Status ---"));
    Serial.print(F("Wi-Fi: "));
    Serial.print(wifiIsConnected() ? "Connected" : "Disconnected");
    Serial.print(F(" (")); Serial.print(wifiGetIP()); Serial.println(F(")"));
    Serial.print(F("Time: "));
    Serial.println(timeManagerGetTimeString());
    Serial.print(F("State: "));
    Serial.println(stateMachineGetStateName());
    Serial.print(F("Proximity: "));
    Serial.println(proximityIsDetected() ? "DETECTED" : "clear");
    Serial.print(F("Schedules: "));
    Serial.println(scheduleManagerGetCount());

  } else if (cmd == "dispense1") {
    Serial.println(F("DEBUG: Sending DISPENSE,1"));
    uartSendCommand(CMD_DISPENSE, 1);

  } else if (cmd == "open1") {
    Serial.println(F("DEBUG: Sending OPEN,1"));
    uartSendCommand(CMD_OPEN, 1);

  } else if (cmd == "close1") {
    Serial.println(F("DEBUG: Sending CLOSE,1"));
    uartSendCommand(CMD_CLOSE, 1);

  } else if (cmd == "buzz") {
    Serial.println(F("DEBUG: Buzzer test"));
    buzzerBeep(1000);

  } else if (cmd == "ping") {
    Serial.println(F("DEBUG: Pinging C3"));
    uartSendCommand(CMD_PING, 0);

  } else if (cmd == "sync") {
    Serial.println(F("DEBUG: Force backend sync"));
    apiClientForceSync();

  } else if (cmd == "wifi") {
    Serial.print(F("WiFi State: "));
    switch (wifiGetState()) {
      case WIFI_DISCONNECTED: Serial.println(F("DISCONNECTED")); break;
      case WIFI_CONNECTING:   Serial.println(F("CONNECTING")); break;
      case WIFI_CONNECTED:    Serial.print(F("CONNECTED — ")); Serial.println(wifiGetIP()); break;
      case WIFI_AP_MODE:      Serial.print(F("AP MODE — ")); Serial.println(wifiGetIP()); break;
    }

  } else if (cmd == "forget") {
    Serial.println(F("Forgetting WiFi credentials and restarting AP..."));
    wifiForgetNetwork();

  } else if (cmd == "help") {
    Serial.println(F("Commands: status, wifi, forget, dispense1, open1, close1, buzz, ping, sync, help"));

  } else {
    Serial.print(F("Unknown command: "));
    Serial.println(cmd);
  }
}

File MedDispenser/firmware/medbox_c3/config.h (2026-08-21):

/*
 * MedBox ESP32-C3 — Configuration
 * =================================
 * Pin assignments, servo angle constants, and module-to-GPIO mapping.
 *
 * STATUS: GPIO assignments are NOT FINALIZED.
 * ESP32-C3 SuperMini has limited GPIOs. Strapping pins: GPIO2, GPIO8, GPIO9.
 * Avoid GPIO2 and GPIO8 for servo signals if possible.
 */

#ifndef MEDBOX_C3_CONFIG_H
#define MEDBOX_C3_CONFIG_H

// ── Board: ESP32-C3 SuperMini ──────────────────────────────────────────────
// Typical usable GPIOs: 0, 1, 2, 3, 4, 5, 6, 7, 8, 9, 10, 20, 21
// GPIO2 = boot strapping (avoid for critical signals)
// GPIO8 = boot strapping (avoid for critical signals)
// GPIO9 = boot button (usable but be aware)
// GPIO20/21 = default UART0 (used for debug / S3 comms)

// ── UART from ESP32-S3 ────────────────────────────────────────────────────
// Header labels on C3 SuperMini: RX = GPIO 20, TX = GPIO 21
#define C3_UART_RX_PIN        20   // C3 RX ← S3 TX (GPIO 17)
#define C3_UART_TX_PIN        21   // C3 TX → S3 RX (GPIO 18)
#define C3_UART_BAUD          115200

// ── Servo GPIO Map ────────────────────────────────────────────────────────
// Format: { dispenser_pin, hatch_pin } per module
// Module 1 = Main module, Module 2-3 = Expansion modules

// Module 1 (Main)
#define SERVO_M1_DISPENSER_PIN  0
#define SERVO_M1_HATCH_PIN      1

// Module 2 (Expansion)
#define SERVO_M2_DISPENSER_PIN  3
#define SERVO_M2_HATCH_PIN      4

// Module 3 (Expansion)
#define SERVO_M3_DISPENSER_PIN  5
#define SERVO_M3_HATCH_PIN      6

// ── Servo Angle Constants ─────────────────────────────────────────────────
// These are placeholder values — MUST be calibrated experimentally.

// Hatch positions
#define HATCH_CLOSED_ANGLE    0     // Hatch closed position (degrees)
#define HATCH_OPEN_ANGLE      90    // Hatch open position (degrees)

// Dispenser 360° Revolution Constants (SG90R 360° Continuous Rotation)
#define DISPENSER_HOME_ANGLE     0     // Home position
#define DISPENSER_SPEED_FORWARD  180   // Full speed forward for SG90R 360° rotation
#define DISPENSER_SPEED_STOP     90    // Neutral / Stop position for SG90R 360°
#define DISPENSER_REV_TIME_MS    2400  // Milliseconds required for 1 full 360° physical revolution

// ── Servo Timing ──────────────────────────────────────────────────────────
#define SERVO_MIN_PULSE_US    500   // Typical SG90-class min pulse
#define SERVO_MAX_PULSE_US    2400  // Typical SG90-class max pulse
#define SERVO_MOVE_DELAY_MS   300   // Time to allow servo to reach position
#define SERVO_DETACH_DELAY_MS 500   // Delay before detaching servo (save power)

// ── Module Count ──────────────────────────────────────────────────────────
#define NUM_MODULES           3     // Max supported modules (1 main + 2 expansion)

// ── System ───────────────────────────────────────────────────────────────
#define SERIAL_DEBUG_BAUD     115200

#endif // MEDBOX_C3_CONFIG_H

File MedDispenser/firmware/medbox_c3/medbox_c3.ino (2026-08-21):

/*
 * MedBox ESP32-C3 — Servo Controller Firmware
 * =============================================
 * Dedicated actuator controller: receives UART commands from ESP32-S3,
 * drives dispenser and hatch servos for all medication modules.
 *
 * Arduino IDE Board: ESP32-C3 Dev Module (or SuperMini variant)
 */

#include "config.h"
#include "uart_handler.h"
#include "servo_controller.h"

// Copy from firmware/shared/ — keep in sync with canonical version
#include "protocol.h"

void setup() {
  // Debug serial (USB)
  Serial.begin(SERIAL_DEBUG_BAUD);
  delay(500);
  Serial.println(F("=== MedBox C3 Servo Controller Starting ==="));

  // Initialize subsystems
  servoControllerInit();
  uartHandlerInit();

  Serial.println(F("=== MedBox C3 Ready ==="));
}

void handleSerialDebug() {
  if (!Serial.available()) return;

  String cmd = Serial.readStringUntil('\n');
  cmd.trim();

  if (cmd == "open1") {
    Serial.println(F("DEBUG: Opening hatch M1"));
    servoOpenHatch(1);
  } else if (cmd == "close1") {
    Serial.println(F("DEBUG: Closing hatch M1"));
    servoCloseHatch(1);
  } else if (cmd == "dispense1") {
    Serial.println(F("DEBUG: Dispensing M1"));
    servoDispense(1);
  } else if (cmd == "home1") {
    Serial.println(F("DEBUG: Homing M1"));
    servoHome(1);
  } else if (cmd == "help") {
    Serial.println(F("C3 Commands: open1, close1, dispense1, home1"));
  } else if (cmd.length() > 0) {
    Serial.print(F("Unknown C3 command: "));
    Serial.println(cmd);
  }
}

void loop() {
  // Check for incoming commands from S3
  uartHandlerUpdate();

  // Process any pending servo movements
  servoControllerUpdate();

  // Serial debug commands from C3 USB Serial Monitor
  handleSerialDebug();
}

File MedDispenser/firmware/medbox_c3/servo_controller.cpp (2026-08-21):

/*
 * MedBox — Servo Controller
 * Dispenser: 1 revolution cycle (0° -> 180° -> 0°) per pill requested.
 * Hatch: 90° open, 0° closed.
 */

#include "servo_controller.h"
#include "config.h"
#include <ESP32Servo.h>

// Dedicated Servo objects per module
static Servo _m1Dispenser;  // GPIO 0
static Servo _m1Hatch;      // GPIO 1

static Servo _m2Dispenser;  // GPIO 3
static Servo _m2Hatch;      // GPIO 4

static Servo _m3Dispenser;  // GPIO 5
static Servo _m3Hatch;      // GPIO 6

// Helper to get dispenser servo by module ID
static Servo* _getDispenser(uint8_t moduleId) {
  if (moduleId == 1) return &_m1Dispenser;
  if (moduleId == 2) return &_m2Dispenser;
  if (moduleId == 3) return &_m3Dispenser;
  return nullptr;
}

// Helper to get hatch servo by module ID
static Servo* _getHatch(uint8_t moduleId) {
  if (moduleId == 1) return &_m1Hatch;
  if (moduleId == 2) return &_m2Hatch;
  if (moduleId == 3) return &_m3Hatch;
  return nullptr;
}

// Rotate DIY modified 360° dispenser servo 1 full revolution, then detach to hard-stop motor
static void _rotatePillRevolution(Servo& dispenser, int pin) {
  dispenser.attach(pin);
  dispenser.write(DISPENSER_SPEED_FORWARD); // 180° = Full speed spin
  delay(DISPENSER_REV_TIME_MS);             // 2400ms = 1 full 360° revolution
  dispenser.detach();                       // Cut signal ➔ Motor stops instantly!
  delay(300);
}

void servoControllerInit() {
  // Attach hatch servos to 0° home position
  _m1Hatch.attach(SERVO_M1_HATCH_PIN);
  _m2Hatch.attach(SERVO_M2_HATCH_PIN);
  _m3Hatch.attach(SERVO_M3_HATCH_PIN);

  _m1Hatch.write(HATCH_CLOSED_ANGLE); // 0°
  _m2Hatch.write(HATCH_CLOSED_ANGLE); // 0°
  _m3Hatch.write(HATCH_CLOSED_ANGLE); // 0°

  // Dispenser servos remain detached while idle to prevent continuous spin
  _m1Dispenser.detach();
  _m2Dispenser.detach();
  _m3Dispenser.detach();

  Serial.println(F("Servo controller initialized (DIY 360° auto-detach stop)"));
}

void servoControllerUpdate() {
  // Non-blocking update loop
}

void servoDispense(uint8_t moduleId, uint8_t count) {
  if (count == 0) count = 1;

  Serial.print(F("Dispensing M"));
  Serial.print(moduleId);
  Serial.print(F(" → "));
  Serial.print(count);
  Serial.println(F(" pill(s)"));

  Servo* d = _getDispenser(moduleId);
  if (!d) return;

  int pin = (moduleId == 1) ? SERVO_M1_DISPENSER_PIN :
            (moduleId == 2) ? SERVO_M2_DISPENSER_PIN : SERVO_M3_DISPENSER_PIN;

  // Perform 1 full 360° revolution (attach ➔ spin ➔ detach) for each pill
  for (uint8_t i = 0; i < count; i++) {
    Serial.print(F("Pill #"));
    Serial.println(i + 1);
    _rotatePillRevolution(*d, pin);
  }
}

void servoOpenHatch(uint8_t moduleId) {
  Serial.print(F("Opening hatch M"));
  Serial.println(moduleId);

  Servo* h = _getHatch(moduleId);
  if (h) {
    h->write(HATCH_OPEN_ANGLE);  // 90°
  }
}

void servoCloseHatch(uint8_t moduleId) {
  Serial.print(F("Closing hatch M"));
  Serial.println(moduleId);

  Servo* h = _getHatch(moduleId);
  if (h) {
    h->write(HATCH_CLOSED_ANGLE); // 0°
  }
}

void servoHome(uint8_t moduleId) {
  Serial.print(F("Homing M"));
  Serial.println(moduleId);

  Servo* d = _getDispenser(moduleId);
  Servo* h = _getHatch(moduleId);

  if (d) d->detach();                  // Hard stop continuous 360° dispenser motor
  if (h) h->write(HATCH_CLOSED_ANGLE);   // Close hatch (0°)
}

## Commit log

2026-08-13 Update fmt.Println message from 'Hello' to 'Goodbye'
2026-08-15 Added test buttons
2026-08-15 Added KiCAD Files
    [MedDispenser.kicad_pcb, MedDispenser.kicad_sch, main_box.kicad_sch]
2026-08-21 web updates, sync fix process
    [api_client.cpp, config.h, protocol.h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]
